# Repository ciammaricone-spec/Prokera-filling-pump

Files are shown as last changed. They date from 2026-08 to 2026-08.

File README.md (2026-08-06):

# Prokera Filling Pump

Control station for a Prokera filling pump using an Arduino Nano R4, a CL42T stepper driver, a physical press switch, and a Windows graphical control panel.

## Active Version

Active Nano R4 sketch/app label:

`V3-11 Nano R4 Peristaltic filling by G.C.`

Includes:

- Arduino Nano R4 firmware.
- Windows graphical pump control app.
- RUN, PURGE, STOP, Save, Read, and Clear Log controls.
- PURGE app button: fixed 15000 steps using the current speed.
- Physical press switch short press: normal run.
- Physical press switch long press, 3 seconds or more: purge run.
- Restored working Nano R4 pin map: `PUL-` on `D2`, `DIR-` on `A5`.
- CL42T ENA is kept enabled. If ENA causes disable behavior, leave ENA disconnected.
- EEPROM save verification using `EEPROM.put()` / `EEPROM.get()`: the controller prints `OK SAVE` or `ERR SAVE VERIFY` after saving settings.
- The Windows Save button uses one atomic `SET CONFIG <steps> <speed>` command to avoid back-to-back EEPROM writes.
- Standby switch guard: fixed emergency NC mode on `A2`; short press runs on release, press longer than 3 seconds purges while held.
- Longer switch filtering to prevent unintended standby starts from cable noise.
- Silent VBS launcher so the PowerShell console stays hidden.
- Pharmaceutical laboratory style technical manual.

The purge run does not overwrite the normal configured step count.

## Mechanical Model

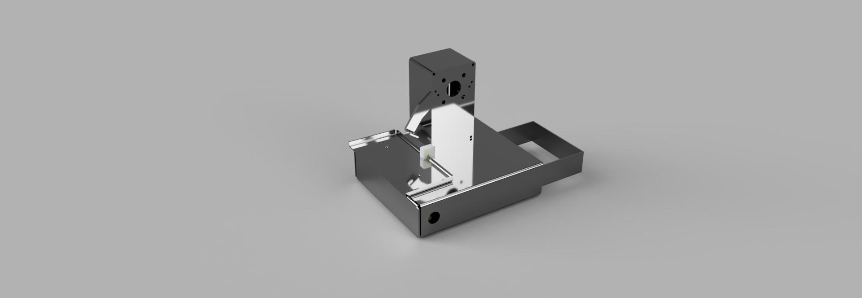
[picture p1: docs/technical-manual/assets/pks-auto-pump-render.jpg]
Prokera automatic pump mechanical render


## Contents

- `firmware/Nano_R4_Pump_Control/Nano_R4_Pump_Control.ino` - Arduino Nano R4 firmware.
- `windows-app/Nano_R4_Pump_Control/` - Nano R4 Windows app, launchers, and app README.
- `docs/technical-manual/` - current technical manual document.
- `docs/technical-manual/` - Nano R4 pharmaceutical laboratory style technical manual.
- `docs/technical-manual/assets/configuration-1.step` - STEP mechanical configuration file.

## Default Settings

- Normal run: `32000` steps.
- Purge: `15000` fixed steps.
- Speed: `210 us`.
- USB serial: `115200`.
- Press switch short press: normal run.
- Press switch long press, 3 seconds or more: purge run.
- Switch input guard: released state must be stable for 2 seconds before arming, and press must last at least 350 ms.

## CL42T Common-Anode Wiring

| CL42T | Arduino Nano R4 |
| --- | --- |
| `PUL+` | regulated `5V` |
| `PUL-` | `D2` |
| `DIR+` | regulated `5V` |
| `DIR-` | `A5` |
| `ENA+` | regulated `5V`, optional |
| `ENA-` | `A1`, optional. Leave disconnected if it disables the driver. |
| Press switch | NC contact to `A2`, COM to `GND` |

Do not use 24V directly with Arduino pins. For direct Arduino-to-CL42T wiring, use regulated 5V on `PUL+`, `DIR+`, and `ENA+`.

For long switch cables, add an external `10k` pull-up from `A2` to `5V`. If standby starts still occur, add a `0.1 uF` capacitor from `A2` to `GND`. If the switch is wired to NO instead of NC, swap `SWITCH_RELEASED_LEVEL` and `SWITCH_PRESSED_LEVEL` in the sketch.

## How To Use

1. Open Arduino IDE.
2. Upload `firmware/Nano_R4_Pump_Control/Nano_R4_Pump_Control.ino` to the Arduino Nano R4.
3. Close Arduino IDE Serial Monitor.
4. Connect the Nano R4 by USB.
5. Run `windows-app/Nano_R4_Pump_Control/Run_NanoR4PumpControl_Silent.vbs`.
6. Select the Nano R4 COM port and press `Connect`.
7. Press `Read`, set `Steps` and `Speed us` if needed, then use `RUN`, `PURGE`, or the physical switch.

## Physical Press Switch

- Less than 3 seconds: normal run.
- 3 seconds or more: purge, fixed 15000 steps.
- The action starts when the switch is released.

## Serial Commands

Baudrate: `115200`

```text
GET
SET STEPS 32000
SET SPEED 210
RUN
RUN 32000 210
PURGE
STOP
PING
```

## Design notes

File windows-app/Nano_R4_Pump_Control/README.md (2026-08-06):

# V3-8 Nano R4 Peristaltic filling by G.C.

USB/COM pump controller for **Arduino Nano R4** and CL42T driver.

Version 3.8 keeps the working Nano pin map and uses the NC switch guard so the pump only starts from a confirmed physical switch contact or an explicit USB command.

## Files

- `Nano_R4_Pump_Control/Nano_R4_Pump_Control.ino`: main firmware.
- `Nano_R4_CL42T_Common_Anode_Test/Nano_R4_CL42T_Common_Anode_Test.ino`: simple motion test.
- `NanoR4PumpControl.ps1`: Windows PowerShell/WinForms app.
- `Run_NanoR4PumpControl_Silent.vbs`: opens the app without showing PowerShell.

## Arduino IDE

Install the Arduino UNO R4 Boards core, then select:

```text
Board: Arduino Nano R4
Port: COM for Nano R4
Upload: normal Upload button
```

## CL42T Common Anode Wiring

Start with ENA disconnected.

```text
PUL+ -> regulated +5V
DIR+ -> regulated +5V
ENA disconnected

PUL- -> Nano R4 D2
DIR- -> Nano R4 A5

Press switch NC -> A2
Press switch COM -> GND
```

If ENA control is needed later:

```text
ENA+ -> regulated +5V
ENA- -> Nano R4 A1, optional. If ENA causes the driver to disable, leave ENA disconnected.
```

## Power

Use the 24V supply for CL42T motor power. Use a buck converter set to 5.0V for Nano R4 logic/signal power if needed. Do not connect 24V to Nano R4 I/O pins.

## Default Settings

```text
Steps = 32000
Purge = 15000 steps
Speed = 210 us
Baudrate = 115200
```

## Test First

Upload `Nano_R4_CL42T_Common_Anode_Test.ino` first.

If the test does not move:

1. Keep ENA disconnected.
2. Verify `PUL+` and `DIR+` have +5V.
3. Verify `PUL-` is on `D2`.
4. Verify `DIR-` is on `A5`.
5. Verify CL42T motor power, alarm status, and motor wiring.

If the test moves, upload `Nano_R4_Pump_Control.ino` and use the Windows app.

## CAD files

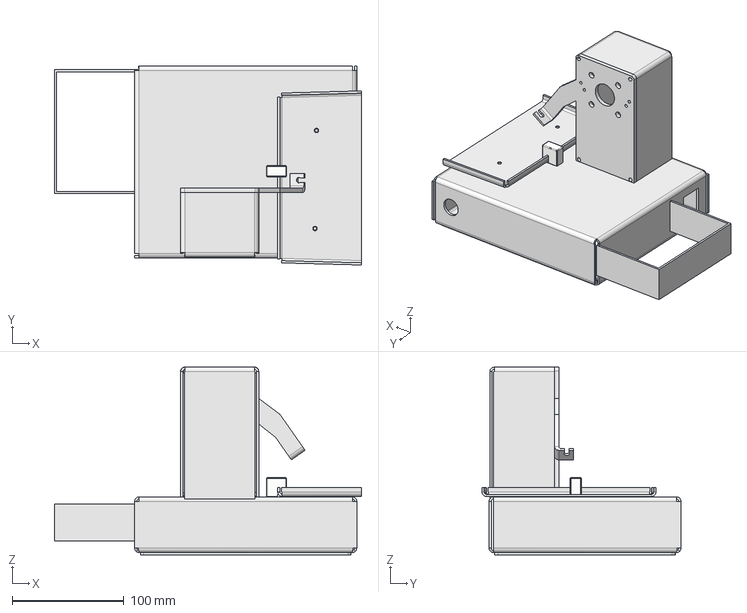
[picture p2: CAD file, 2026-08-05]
docs/technical-manual/assets/configuration-1.step
275.1 x 178.3 x 168.2 mm

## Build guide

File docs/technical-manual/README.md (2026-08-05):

# Technical Manual

This folder contains the current Prokera Filling Pump technical manual document.

## File

- `PFP-rev2_8-4-2026.docx`
- `assets/configuration-1.step` - STEP mechanical configuration file.
- `assets/pks-auto-pump-render.jpg` - mechanical render image.

## Mechanical Render

Prokera automatic pump mechanical render

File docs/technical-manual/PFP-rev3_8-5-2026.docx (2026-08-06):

PROKERA PERISTALTIC FILLING PUMP STATION

Equipment Documentation Manual

Microcontroller-Based Filling Pump for Prokera Production Support

User-End Interface and Mechanical Layout Drawing Placeholder Included

Document Field | Value
Equipment Name | Prokera Peristaltic Filling Pump Station
Document Type | Equipment Documentation Manual
Revision | R4 - Interface and Drawings Updated
Prepared For | BioTissue production and calibration personnel
Operation Mode | Standalone production operation using the activation switch

1. Purpose

This manual documents the Prokera Peristaltic Filling Pump Station used for controlled dispensing during Prokera production support. It describes the equipment configuration, normal operating procedure, calibration and service interface, maintenance, troubleshooting, and bill of materials.

2. System Overview

The equipment is a compact peristaltic filling pump station controlled by an internal microcontroller. During normal production use, the operator runs the equipment as a standalone unit using the external activation switch. The Windows application is not used during routine filling.

Normal operation note
The communication connector is hidden inside the equipment case and is accessible only to an authorized calibration technician after removing the bottom cover. The cover must be reinstalled and secured before returning the equipment to normal operation.

3. Safety and Handling

Use the equipment only for the intended Prokera filling support process.

Do not operate the pump with loose covers, exposed wiring, or damaged tubing.

Keep fingers, loose clothing, and tools away from the pump head while the motor is active.

Do not spray cleaning fluid directly into electrical openings or onto the internal service connector.

Only authorized calibration or service personnel may access internal electrical connections.

4. Main Components

Item | Description | Function
Pump head | Peristaltic pump assembly | Moves liquid through disposable tubing without contacting the pump mechanism.
Motor | Pump drive motor | Provides controlled rotation for fill and purge cycles.
Activation switch | External operator switch | Starts normal fill or purge/prime sequence depending on press duration.
Microcontroller | Internal control board | Stores parameters and controls pump timing, speed, direction, and service logic.
Power supply | Regulated DC power | Provides controlled power for the internal electronics and pump drive.
Tubing | Disposable process tube | Single-use fluid path for one lot only.

5. Electrical Configuration

The pump station uses a closed-loop stepper motor controlled through a CL42T V4.1 driver. The microcontroller sends step and direction signals to the driver using a common-anode input arrangement. Low-voltage control wiring must remain separated from AC mains wiring.

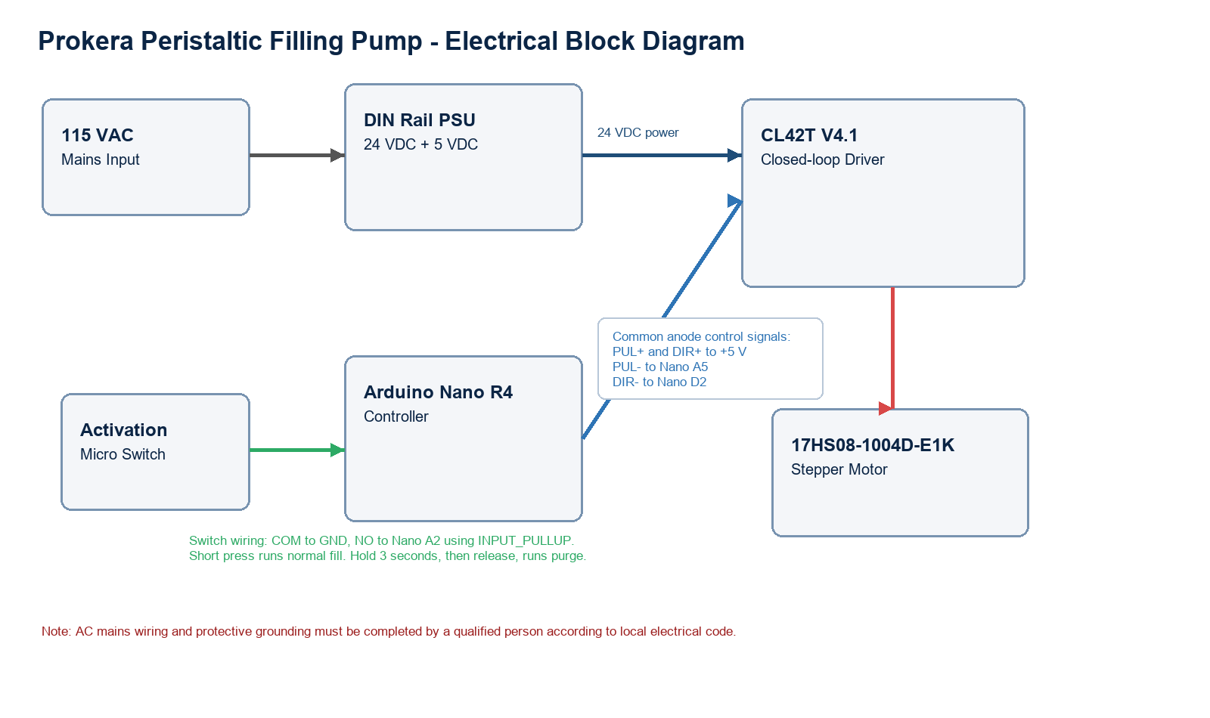
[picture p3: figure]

Figure 2. Electrical block diagram for the microcontroller, CL42T driver, motor, activation switch, and dual-output power supply.

5.1 Power Distribution

AC input: 100-240 VAC supply input, typically operated from 115-120 VAC in the intended location.

24 VDC output: connect to the CL42T driver power input as specified by the driver manual.

5 VDC output: connect to the microcontroller 5 V input/GND and to the CL42T signal common anode inputs as described below.

0 V reference: the 5 VDC supply negative, microcontroller GND, and low-voltage control references must be common where required for signal operation.

5.2 CL42T Common-Anode Signal Wiring

CL42T terminal | Connection | Function
PUL+ | +5 VDC regulated | Common anode for step input
PUL- | Microcontroller A5 | Step pulse. Active LOW in current firmware.
DIR+ | +5 VDC regulated | Common anode for direction input
DIR- | Microcontroller D2 | Direction control
ENA+ | +5 VDC regulated, optional | Enable common anode if enable input is used
ENA- | Microcontroller A1, optional | Driver enable control. Leave ENA disconnected during initial test if driver enables by default.
VDC / GND | 24 VDC supply output | Driver motor power input
Motor connector | StepperOnline closed-loop motor cable | Motor phase and encoder feedback per CL42T/motor documentation

5.3 Activation Switch Wiring

The activation switch is wired as a low-voltage dry-contact input. Do not route mains voltage through the microcontroller input circuit.

Switch COM: connect to microcontroller GND.

Switch NO: connect to microcontroller A2.

Firmware input mode: INPUT_PULLUP. The input is normally HIGH and becomes LOW when pressed.

Short press and release: normal run using configured steps.

Press and hold for at least 3 seconds, then release: purge run using fixed 15,000 steps.

6. Firmware and Default Settings

Serial command set: GET, SET STEPS <value>, SET SPEED <value>, RUN, RUN <steps> <speed_us>, PURGE, STOP, and PING.

Parameter | Default / Range | Notes
Firmware label | V3-0 Nano R4 Peristaltic filling by G.C. | Displayed by firmware and used as the active sketch version label.
Serial baud rate | 115200 | Used by Windows application over USB COM port.
Default fill steps | 32,000 | Stored in controller memory when Save is used.
Allowed fill steps | 10 to 50,000 | Firmware rejects values outside this range.
Default speed | 210 us | Microseconds between step events; lower value is faster.
Allowed speed | 210 to 5,000 us | Increase value for slower motion or difficult fluids.
Purge | 15,000 steps fixed | Purge does not change the saved fill quantity.
Activation hold time | 3,000 ms | Hold switch at least 3 seconds to select purge.

7. Normal Operating Procedure

7.1 Startup

Verify that the unit is clean, dry, and visually intact.

Install a new tube before beginning a new lot.

Confirm that the tube is properly seated in the pump head and connected to the process path.

Confirm that the bottom cover is installed and secured.

Power on the equipment and verify that the unit is ready for standalone operation.

7.2 Purge / Prime

Purge / Prime must be performed before the first normal filling cycle each time a new tube is installed. The operator must also repeat purge if visible bubbles remain in the tube.

Hold the activation switch for at least 3 seconds to initiate the purge / prime cycle.

Observe the tube during purge and confirm that liquid fills the tube path.

If bubbles remain visible, repeat the purge / prime cycle.

Begin normal filling only after the tube is completely primed and no bubbles are visible.

7.3 Normal Fill

Place the receiving container or process target in the correct filling position.

Press and release the activation switch briefly to start one normal fill cycle.

Allow the pump to complete the programmed cycle without interrupting the equipment.

Inspect the dispensed fill and continue only if the result is acceptable for the process.

7.4 Tubing Use Per Lot

Tubing requirement
The tube is single-use only and may be used for one lot only. A new tube must be installed at the start of each lot, purged before the first normal filling cycle, and removed and discarded after the lot is complete.

7.5 Shutdown

Complete the final fill cycle for the lot.

Remove and discard the used tube according to the applicable procedure.

Clean accessible equipment surfaces as required.

Power off the equipment when work is complete.

8. Windows User-End Interface

The Windows user-end interface displays machine state, current settings, progress, operating commands, and communication log messages. The interface layout shown below is the released V3-0 Nano Peristaltic filling by G.C. screen. (can be downloaded here: https://github.com/ciammaricone-spec/Prokera-filling-pump/blob/main/windows-app/Nano_R4_Pump_Control/Run_NanoR4PumpControl_Silent.vbs)

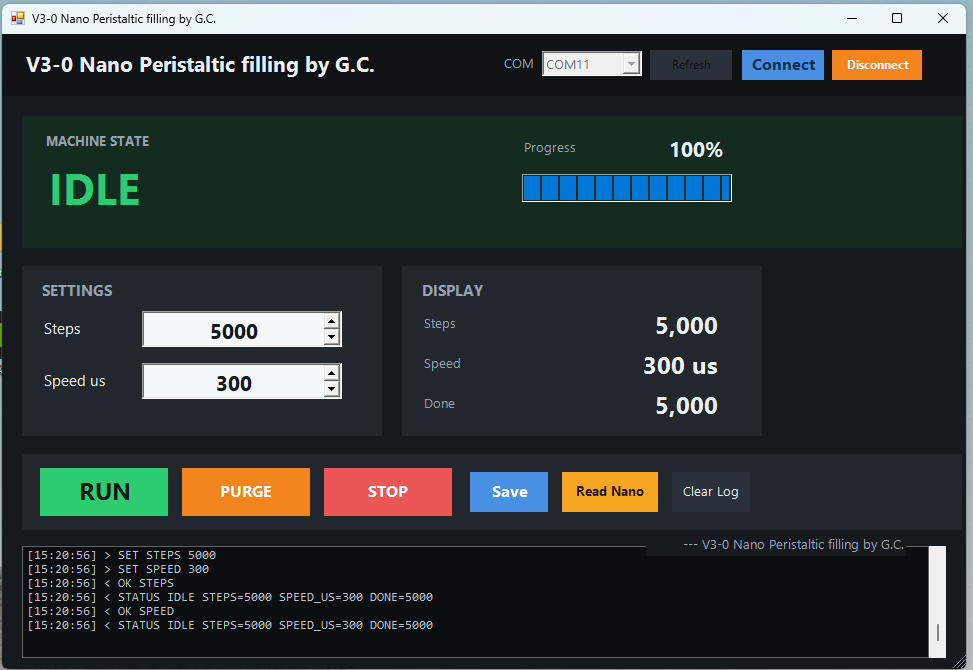
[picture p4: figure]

Figure 1. Windows user-end interface screen.

User-End Area | Displayed Function
Machine State | Shows current status such as IDLE and displays progress percentage.
Settings | Allows entry of Steps and Speed us values used by the pump cycle.
Display | Shows current Steps, Speed, and Done values read from the controller.
Command Buttons | Provides RUN, PURGE, STOP, Save, Read Nano, and Clear Log controls.
Communication Log | Shows command and status messages returned by the controller.

8.1 Operator Controls

Control | Use
Connect | Open the selected controller COM port.
Read Nano | Request current controller status and saved settings.
Steps | Set target step count for the normal fill run.
Speed us | Set the step interval in microseconds. Higher value equals slower movement.
Save | Save the displayed steps and speed to the controller.
RUN | Start a normal fill using the current steps and speed.
PURGE | Run 15,000 fixed steps for priming or clearing tubing.
STOP | Stop motion as soon as the controller receives the command.
Clear Log | Clear the application log display.

9. Calculation Formulas

The following formulas are used to establish and verify pump settings during calibration. Actual production settings must be confirmed by authorized calibration personnel using measured dispense results.

Calculation | Formula | Purpose
Steps per mL | Steps per mL = Calibration Steps / Measured Volume (mL) | Determines the pump calibration factor from a measured dispense test.
Target Steps | Target Steps = Target Fill Volume (mL) x Steps per mL | Calculates the Steps value entered in the user-end interface.
Measured Volume | Measured Volume (mL) = Dispensed Weight (g) / Liquid Density (g/mL) | Converts gravimetric verification results to volume.
Approximate Fill Time | Fill Time (sec) = (Steps x Speed us) / 1,000,000 | Estimates cycle duration based on the selected Steps and Speed us settings.
Flow Rate | Flow Rate (mL/sec) = Dispensed Volume (mL) / Fill Time (sec) | Verifies dispense rate during calibration or service testing.
Percent Error | Percent Error = ((Measured Volume - Target Volume) / Target Volume) x 100 | Documents how close the measured dispense is to the target fill volume.

Formula note
Speed us is the microsecond timing value shown in the interface. Lower Speed us values increase motor step rate; higher values decrease motor step rate. Calibration acceptance limits must follow the approved process requirement.

10. Calibration and Verification

Remove the bottom cover only if authorized for calibration or service.

Connect the Windows service application to the internal communication connector.

Read current parameters and verify that the expected configuration is loaded.

Run controlled test cycles as required by the calibration procedure.

Adjust parameters only when required and document the change.

Disconnect the service cable, reinstall the bottom cover, and secure the equipment before returning it to normal operation.

10.1 Calibration Workflow

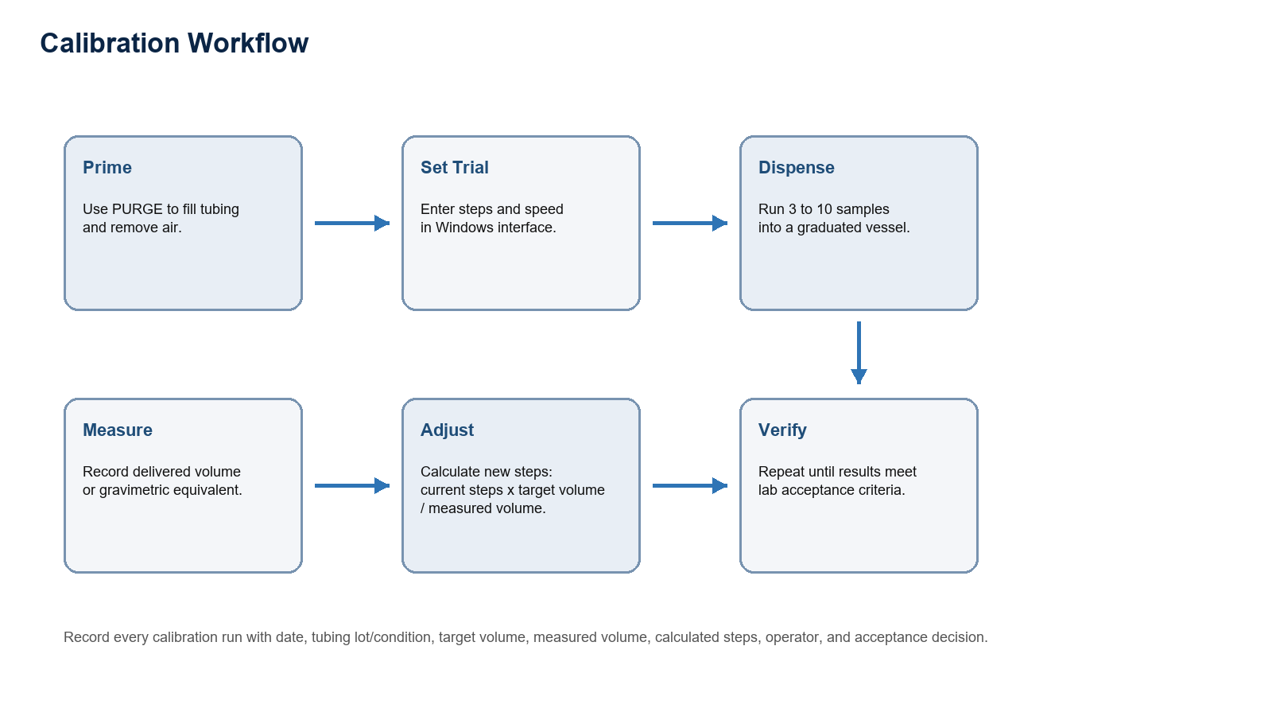
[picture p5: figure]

Figure 3. Calibration workflow.

10.2 Calibration Conditions

Use the same tubing type, tubing size, pump head compression, liquid, speed, and outlet height that will be used during operation.

Prime the line before collecting data.

Use a calibrated balance or volumetric device appropriate for the target fill volume.

Define acceptance criteria before calibration, such as mean volume tolerance and repeatability requirement.

10.3 Example Step Adjustment Calculation

New Steps = Current Steps x Target Volume / Measured Volume

Example: if 32,000 steps dispense 9.60 mL and the target is 10.00 mL, then New Steps = 32,000 x 10.00 / 9.60 = 33,333 steps.

10.4 Calibration Record

Run | Target volume | Current steps | Measured volume | Calculated steps | Operator | Accept / Reject
1
2
3
Mean

11. Mechanical Layout Drawings

DRAWINGS COMING SOON..
Mechanical layout drawings will be inserted in this section when released. This placeholder intentionally remains in the manual so reviewers know the drawing package is pending.

The following approved project artifacts should be inserted before document release:

Electrical wiring drawing with terminal numbers and wire colors.

Mechanical drawing of stainless enclosure, pump head mount, panel openings, and DIN rail layout.

Photographs of internal wiring after final assembly.

Photographs of final exterior front panel and tubing path.

Windows interface screenshots showing connected, idle, running, purge, and alarm/error states.

12. Cleaning and Maintenance

12.1 Routine Cleaning

Clean accessible surfaces before and after each use according to the applicable cleanroom cleaning procedure.

Use IPA alcohol wipes on accessible external surfaces.

Do not spray IPA directly into the pump head, electrical openings, switch, or internal connector area.

Allow all surfaces to fully dry before use.

Do not open the case or remove covers as part of routine cleaning.

12.2 Preventive Maintenance Schedule

Frequency | Inspection | Acceptance Criteria
Before each use | Inspect tubing, pump head, switch, and accessible surfaces. | No visible damage, contamination, loose parts, or tubing defects.
Before each use and weekly | Check power cable, external case, and labels. | Cable and case are intact; labels remain legible.
Per PM schedule | Verify pump function and calibration status. | Equipment performs programmed cycles within accepted limits.
After maintenance | Perform functional check before returning to use. | Normal fill and purge / prime functions operate as expected.
Before use | Visual inspection of enclosure, tubing, switch, and cables | No damage, moisture, loose fittings, or exposed conductors
Before batch or study | Run calibration or verification shot | Within predefined fill tolerance
Monthly or per use rate | Inspect terminal blocks, power supply mount, driver mount, and labels | Secure, legible, and free of corrosion
After maintenance | Functional test: Read, Run, Purge, Stop, and switch activation | All functions respond correctly

13. Troubleshooting

Symptom | Possible Cause | Corrective Action
Pump does not start | Power is off, switch issue, or internal fault. | Verify power, inspect external switch condition, and remove from service if fault remains.
Inconsistent fill | Tube not seated, bubbles present, or parameter issue. | Reseat tube, perform purge / prime, and request calibration review if condition persists.
Visible bubbles | New tube not fully primed or air in fluid path. | Repeat purge / prime until no bubbles are visible before normal filling.
Service application cannot connect | Internal connector, cable, or communication setting issue. | Authorized technician verifies connection after opening bottom cover.
App cannot connect | COM port is in use by Arduino IDE or another app. | Close Serial Monitor, close other pump app windows, reconnect USB, then select the COM port again.
Upload denied on COM port | Windows application or Serial Monitor is holding the port. | Disconnect/close the app before uploading firmware.
Motor energized but not moving | Incorrect common-anode wiring, wrong pulse pin, disabled driver, or speed too fast. | Verify PUL+ and DIR+ to +5 V, PUL- to A5, DIR- to D2, ENA state, and start with slower speed such as 1000 us.
Motor vibrates only | Direction/step signal issue, motor cable/phase issue, driver current/switch setting mismatch, or mechanical load. | Check CL42T settings, motor cable, common-anode signal wiring, and pump head load.
Inconsistent fill volume | Air in line, tubing slip, changing viscosity, worn tubing, or speed too high. | Purge, inspect tubing, reduce speed, and recalibrate under actual process conditions.
Driver alarm | Closed-loop following error, overload, wiring fault, or supply issue. | Stop operation, inspect motor/encoder wiring, mechanical load, supply voltage, and driver documentation.

14. Bill of Materials

Item | Component | Description | Notes
1 | Arduino Nano R4 | Controller powered from regulated 5 VDC. USB used for Windows interface and firmware upload. | Service interface and firmware upload via USB.
2 | Stepper driver | CL42T V4.1 closed-loop stepper driver, operated from 24 VDC in this system.
3 | Motor | StepperOnline 17HS08-1004D-E1K, 1.0 A, 0.14 Nm, closed-loop stepper motor. | Controlled by internal electronics.
4 | Activation switch | Waterproof micro switch, long straight hinge lever, NO/NC/COM wiring, 10 A at 125/250 VAC rating, 30 cm cable. Used only as low-voltage control input in this design. | Short press starts fill; long press starts purge / prime.
5 | Power supply | DIN rail dual output 24 VDC and 5 VDC, 10 W class, input 100-240 VAC. Verify the actual nameplate ratings before installation. | Sized for motor and control electronics.
6 | Enclosure | Custom stainless steel box with appropriate glands, strain relief, grounding, and labeling. | Internal connector is service-access only.
7 | Internal wiring | Rated conductors, ferrules, terminal blocks, protective earth bonding hardware, and separated AC/DC routing.
8 | Pump wetted path | Tubing, fittings, and pump head selected and qualified by laboratory for the intended fluid. | Includes tubing; one use only per lot.
9 | Peristaltic pump head | Tubing-contact pump mechanism. | Supports disposable process tube.

15. Revision Summary

Revision | Description
R4 | Updated manual with Windows interface image and Mechanical Layout Drawings placeholder text: DRAWINGS COMING SOON..
Prior updates | Standalone operation clarified; routine production does not use the Windows application. Tubing single-use per lot and purge / prime requirements added.
Rev2 + technical updates | Added missing technical content: electrical configuration, firmware/default settings, operator controls, calibration workflow/record, maintenance checks, technical troubleshooting, and detailed component table.

Prokera Peristaltic Filling Pump Station Equipment Documentation Manual

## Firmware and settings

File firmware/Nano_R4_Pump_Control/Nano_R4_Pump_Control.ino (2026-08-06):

// =====================================================
// NANO R4 PUMP CONTROL STATION + WINDOWS SERIAL APP
//
// CL42T COMMON ANODE 5V WIRING:
// PUL+ / DIR+ -> regulated +5V
// PUL- -> STEP_PUMP
// DIR- -> DIR_PUMP
// ENA is optional. Leave ENA disconnected first for testing.
// If ENA is used: ENA+ -> +5V, ENA- -> ENA_PUMP
//
// PRESS SWITCH:
// Current machine wiring: NC contact to PRESS_SWITCH_PIN, COM to GND.
// Uses INPUT_PULLUP, so released = LOW and pressed/open = HIGH.
// =====================================================

#include <Arduino.h>

#if __has_include(<EEPROM.h>)
#include <EEPROM.h>
#define HAS_EEPROM 1
#else
#define HAS_EEPROM 0
#endif

#define FW_VERSION "V3-11 Nano R4 Peristaltic filling by G.C."

// ---------------- PIN MAP ----------------
#define STEP_PUMP 2
#define DIR_PUMP  A5
#define ENA_PUMP  A1

#define PRESS_SWITCH_PIN A2

// ---------------- LIMITS / DEFAULTS ----------------
const long DEFAULT_PUMP_STEPS = 32000;
const long PURGE_STEPS = 15000;
const unsigned long DEFAULT_PUMP_SPEED_US = 210;

const long MIN_PUMP_STEPS = 10;
const long MAX_PUMP_STEPS = 50000;

const unsigned long MIN_PUMP_SPEED_US = 210;
const unsigned long MAX_PUMP_SPEED_US = 5000;

// ---------------- STEPPER DRIVER LOGIC ----------------
// Common anode: PUL+ / DIR+ to regulated +5V.
// The Nano R4 controls the negative side of each CL42T input.
// Matches the working Nano wiring/test sketch.
#define STEP_IDLE_LEVEL LOW
#define STEP_ACTIVE_LEVEL HIGH

// Keep the CL42T enabled. If ENA causes trouble, leave ENA disconnected.
#define DRIVER_ENABLE_LEVEL HIGH
#define DRIVER_DISABLE_LEVEL HIGH

// If pump turns the wrong way, change this to LOW.
#define PUMP_DIR_CW HIGH

// ---------------- TIMING ----------------
const unsigned long DEBOUNCE_MS = 80;
const unsigned long POST_RUN_LOCKOUT_MS = 500;
const unsigned long PURGE_HOLD_MS = 3000;
const unsigned long SWITCH_MIN_PRESS_MS = 150;

const uint32_t CONFIG_MAGIC = 0x50554D50UL; // "PUMP"
const int EEPROM_ADDR = 0;

struct PumpConfig
{
  uint32_t magic;
  long steps;
  unsigned long speedUs;
};

PumpConfig config;

enum State
{
  IDLE,
  RUN_PUMP
};

State machineState = IDLE;

long pumpStepsDone = 0;
long activeRunSteps = DEFAULT_PUMP_STEPS;
unsigned long lastPumpPulse = 0;
unsigned long runEndedAt = 0;

bool switchStable = LOW;
bool switchPressActive = false;
bool switchLastRaw = HIGH;
bool switchEnabled = true;
bool purgeStartedFromHold = false;
unsigned long switchPressedAt = 0;
unsigned long switchLastRawChangeAt = 0;

String serialLine = "";

bool validSteps(long steps)
{
  return steps >= MIN_PUMP_STEPS && steps <= MAX_PUMP_STEPS;
}

bool validSpeed(unsigned long speedUs)
{
  return speedUs >= MIN_PUMP_SPEED_US && speedUs <= MAX_PUMP_SPEED_US;
}

bool readStoredConfig(PumpConfig &stored)
{
#if HAS_EEPROM
  EEPROM.get(EEPROM_ADDR, stored);
  return stored.magic == CONFIG_MAGIC &&
         validSteps(stored.steps) &&
         validSpeed(stored.speedUs);
#else
  (void)stored;
  return false;
#endif
}

bool writeStoredConfig()
{
#if HAS_EEPROM
  config.magic = CONFIG_MAGIC;
  EEPROM.put(EEPROM_ADDR, config);
  delay(250);

  PumpConfig verify;
  if (!readStoredConfig(verify))
    return false;

  return verify.steps == config.steps &&
         verify.speedUs == config.speedUs;
#else
  return false;
#endif
}

void loadConfig()
{
  PumpConfig stored;

  if (readStoredConfig(stored))
  {
    config = stored;
  }
  else
  {
  config.magic = CONFIG_MAGIC;
  config.steps = DEFAULT_PUMP_STEPS;
  config.speedUs = DEFAULT_PUMP_SPEED_US;
    writeStoredConfig();
  }
}

bool saveConfig()
{
  config.magic = CONFIG_MAGIC;
  return writeStoredConfig();
}

void printSaveResult()
{
  if (saveConfig())
    Serial.println("OK SAVE");
  else
    Serial.println("ERR SAVE VERIFY");
}

void printStatus()
{
  Serial.print("STATUS ");
  Serial.print(machineState == IDLE ? "IDLE" : "RUNNING");
  Serial.print(" STEPS=");
  Serial.print(config.steps);
  Serial.print(" SPEED_US=");
  Serial.print(config.speedUs);
  Serial.print(" DONE=");
  Serial.println(pumpStepsDone);
}

void enablePumpDriver()
{
  digitalWrite(ENA_PUMP, DRIVER_ENABLE_LEVEL);
}

void disablePumpDriver()
{
  digitalWrite(ENA_PUMP, DRIVER_DISABLE_LEVEL);
}

inline void pulseStep(uint8_t pin)
{
  digitalWrite(pin, STEP_ACTIVE_LEVEL);
  delayMicroseconds(100);
  digitalWrite(pin, STEP_IDLE_LEVEL);
  delayMicroseconds(10);
}

void startPumpRun()
{
  activeRunSteps = config.steps;

  if (machineState != IDLE)
  {
    Serial.println("ERR BUSY");
    return;
  }

  enablePumpDriver();
  pumpStepsDone = 0;
  lastPumpPulse = micros();
  digitalWrite(DIR_PUMP, PUMP_DIR_CW);
  machineState = RUN_PUMP;
  Serial.println("RUN START");
}

void startPumpRunFixed(long fixedSteps)
{
  if (machineState != IDLE)
  {
    Serial.println("ERR BUSY");
    return;
  }

  enablePumpDriver();
  activeRunSteps = fixedSteps;
  pumpStepsDone = 0;
  lastPumpPulse = micros();
  digitalWrite(DIR_PUMP, PUMP_DIR_CW);
  machineState = RUN_PUMP;

  Serial.print("PURGE START STEPS=");
  Serial.println(activeRunSteps);
}

void stopPumpRun()
{
  machineState = IDLE;
  runEndedAt = millis();
  Serial.println("RUN STOP");
}

void finishPumpRun()
{
  machineState = IDLE;
  runEndedAt = millis();
  Serial.println("RUN COMPLETE");
}

void handlePressSwitch(unsigned long nowMs)
{
  if (!switchEnabled)
    return;

  bool rawSwitch = digitalRead(PRESS_SWITCH_PIN);

  if (rawSwitch != switchLastRaw)
  {
    switchLastRaw = rawSwitch;
    switchLastRawChangeAt = nowMs;
    return;
  }

  if ((nowMs - switchLastRawChangeAt) < DEBOUNCE_MS)
    return;

  bool switchNow = rawSwitch;

  if (machineState != IDLE ||
      (nowMs - runEndedAt) < POST_RUN_LOCKOUT_MS)
  {
    switchStable = switchNow;
    return;
  }

  if (!switchPressActive &&
      switchStable == LOW &&
      switchNow == HIGH)
  {
    switchPressActive = true;
    purgeStartedFromHold = false;
    switchPressedAt = nowMs;
    Serial.println("SWITCH PRESSED");
  }

  if (switchPressActive &&
      !purgeStartedFromHold &&
      switchNow == HIGH &&
      (nowMs - switchPressedAt) >= PURGE_HOLD_MS)
  {
    purgeStartedFromHold = true;
    switchPressActive = false;
    Serial.println("SWITCH HOLD - PURGE");
    startPumpRunFixed(PURGE_STEPS);
  }

  if (switchPressActive &&
      switchStable == HIGH &&
      switchNow == LOW)
  {
    unsigned long heldMs = nowMs - switchPressedAt;

    switchPressActive = false;

    if (heldMs < SWITCH_MIN_PRESS_MS)
    {
      Serial.println("SWITCH IGNORED");
    }
    else if (heldMs >= PURGE_HOLD_MS)
    {
      Serial.println("SWITCH RELEASE - PURGE");
      startPumpRunFixed(PURGE_STEPS);
    }
    else
    {
      Serial.println("SWITCH RELEASE - RUN");
      startPumpRun();
    }
  }

  switchStable = switchNow;
}

void servicePump(unsigned long nowMicros)
{
  if (machineState != RUN_PUMP)
    return;

  if (pumpStepsDone < activeRunSteps)
  {
    if (nowMicros - lastPumpPulse >= config.speedUs)
    {
      pulseStep(STEP_PUMP);
      lastPumpPulse = nowMicros;
      pumpStepsDone++;
    }
  }
  else
  {
    finishPumpRun();
  }
}

void handleCommand(String line)
{
  line.trim();
  line.toUpperCase();

  if (line.length() == 0)
    return;

  if (line == "PING")
  {
    Serial.println("PONG NANO_R4_PUMP");
    return;
  }

  if (line == "GET")
  {
    printStatus();
    return;
  }

  if (line == "RUN")
  {
    startPumpRun();
    return;
  }

  if (line == "PURGE")
  {
    startPumpRunFixed(PURGE_STEPS);
    return;
  }

  if (line == "SAVE")
  {
    printSaveResult();
    printStatus();
    return;
  }

  if (line == "SWITCH OFF")
  {
    switchEnabled = false;
    switchPressActive = false;
    purgeStartedFromHold = false;
    Serial.println("OK SWITCH OFF");
    return;
  }

  if (line == "SWITCH ON")
  {
    switchEnabled = true;
    switchPressActive = false;
    purgeStartedFromHold = false;
    switchLastRaw = digitalRead(PRESS_SWITCH_PIN);
    switchStable = switchLastRaw;
    switchLastRawChangeAt = millis();
    Serial.println("OK SWITCH ON");
    return;
  }

  if (line.startsWith("RUN "))
  {
    long stepsValue = 0;
    unsigned long speedValue = 0;
    int parsed = sscanf(line.c_str(), "RUN %ld %lu", &stepsValue, &speedValue);

    if (parsed != 2)
    {
      Serial.println("ERR RUN FORMAT");
      return;
    }

    if (!validSteps(stepsValue))
    {
      Serial.println("ERR STEPS RANGE");
      return;
    }

    if (!validSpeed(speedValue))
    {
      Serial.println("ERR SPEED RANGE");
      return;
    }

    config.steps = stepsValue;
    config.speedUs = speedValue;
    printStatus();
    startPumpRun();
    return;
  }

  if (line.startsWith("SET CONFIG "))
  {
    long stepsValue = 0;
    unsigned long speedValue = 0;

    int parsed = sscanf(line.c_str(), "SET CONFIG %ld %lu", &stepsValue, &speedValue);

    if (parsed != 2)
    {
      Serial.println("ERR CONFIG FORMAT");
      return;
    }

    if (!validSteps(stepsValue))
    {
      Serial.println("ERR STEPS RANGE");
      return;
    }

    if (!validSpeed(speedValue))
    {
      Serial.println("ERR SPEED RANGE");
      return;
    }

    config.steps = stepsValue;
    config.speedUs = speedValue;
    printSaveResult();
    printStatus();
    return;
  }

  if (line == "STOP")
  {
    stopPumpRun();
    return;
  }

  if (line.startsWith("SET STEPS "))
  {
    long value = line.substring(10).toInt();

    if (!validSteps(value))
    {
      Serial.println("ERR STEPS RANGE");
      return;
    }

    config.steps = value;
    Serial.println("OK STEPS");
    printSaveResult();
    printStatus();
    return;
  }

  if (line.startsWith("SET SPEED "))
  {
    unsigned long value = (unsigned long)line.substring(10).toInt();

    if (!validSpeed(value))
    {
      Serial.println("ERR SPEED RANGE");
      return;
    }

    config.speedUs = value;
    Serial.println("OK SPEED");
    printSaveResult();
    printStatus();
    return;
  }

  Serial.println("ERR UNKNOWN CMD");
}

void serviceSerial()
{
  while (Serial.available())
  {
    char c = (char)Serial.read();

    if (c == '\r')
      continue;

    if (c == '\n')
    {
      handleCommand(serialLine);
      serialLine = "";
      continue;
    }

    if (serialLine.length() < 80)
      serialLine += c;
  }
}

void setup()
{
  Serial.begin(115200);
  delay(500);

  pinMode(STEP_PUMP, OUTPUT);
  pinMode(DIR_PUMP, OUTPUT);
  pinMode(ENA_PUMP, OUTPUT);
  pinMode(PRESS_SWITCH_PIN, INPUT_PULLUP);

  digitalWrite(STEP_PUMP, STEP_IDLE_LEVEL);
  digitalWrite(DIR_PUMP, PUMP_DIR_CW);
  enablePumpDriver();

  loadConfig();

  switchStable = digitalRead(PRESS_SWITCH_PIN);
  switchLastRaw = switchStable;
  switchLastRawChangeAt = millis();
  switchPressActive = false;
  purgeStartedFromHold = false;
  runEndedAt = millis();

  Serial.println("");
  Serial.println("NANO_R4_PUMP READY");
  Serial.println(FW_VERSION);
  Serial.println("SWITCH MODE=NC_A2_GND RUN_ON_RELEASE PURGE_ON_3S_HOLD");
  printStatus();
}

void loop()
{
  unsigned long nowMicros = micros();
  unsigned long nowMs = millis();

  serviceSerial();
  handlePressSwitch(nowMs);
  servicePump(nowMicros);
}

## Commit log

2026-07-14 Add UNO pump control app and firmware
2026-07-15 Add purge controls and long-press switch behavior
2026-08-04 Prevent unintended switch starts
    [Nano_R4_Pump_Control.ino]
2026-08-04 Keep CL42T enabled and auto-detect switch
2026-08-04 Restore working Nano R4 pin map
2026-08-05 Add mechanical docs assets
    [configuration-1.step]
2026-08-06 Prevent standby switch noise starts
    [Nano_R4_Pump_Control.ino]
2026-08-06 Set Nano R4 switch mode to NC
2026-08-06 Make Nano R4 switch trigger auto-detect
2026-08-06 Restore switch release and purge behavior
2026-08-06 Use fixed NC switch release trigger
    [Nano_R4_Pump_Control.ino]
